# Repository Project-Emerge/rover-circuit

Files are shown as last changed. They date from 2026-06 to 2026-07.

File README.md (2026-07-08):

# Dropbot Circuit Board

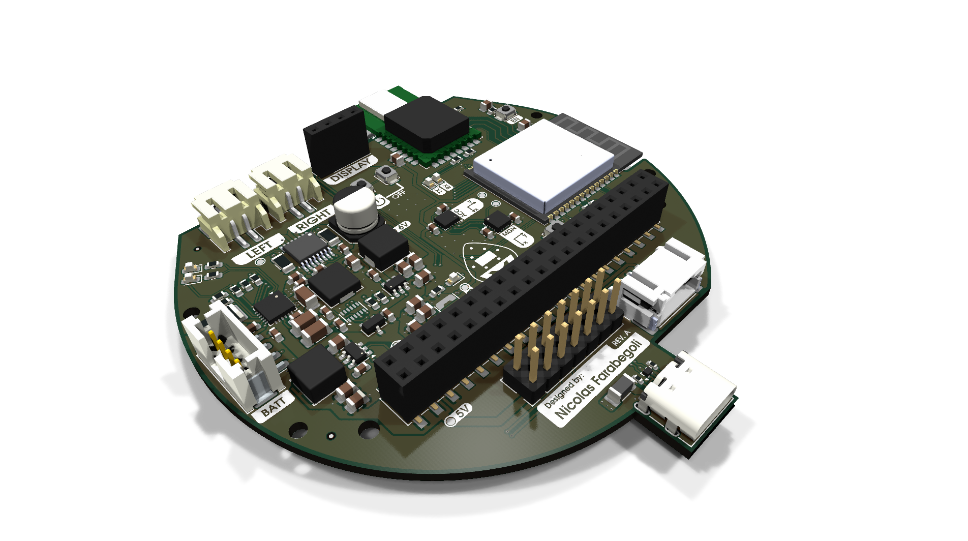
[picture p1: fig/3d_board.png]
3D View of the Board


## Scope of the Board

The Rover Circuit is a comprehensive controller board designed for robotics applications, specifically targeted at robot rovers. A key goal of this project is to make swarm robotics accessible to students, educators, and researchers, providing an affordable and easy-to-use platform for experimenting with multi-agent systems and decentralized control. 

It integrates dual-motor driving capabilities, 2-cell Li-ion battery management with USB-C charging, and provides multiple power domains (3.3V, 5V, 6V) for logic, sensors, and external compute modules like a Raspberry Pi. The board includes I2C and GPIO interfaces to facilitate communication with various sensors and control systems, making it a compact, all-in-one hardware platform for mobile robot development.

## Main Components & Features

* **Espressif ESP32-C6 (Microcontroller)**: The core processing unit of the board, offering Wi-Fi 6, Bluetooth LE, and IEEE 802.15.4 (Zigbee/Thread) connectivity. Its robust wireless capabilities are ideal for inter-robot communication in a swarm network.
* **Decawave DWM1000 (UWB Module)**: An Ultra-Wideband transceiver module designed for precise indoor localization, spatial awareness, and ranging between rovers. Crucial for coordinated swarm movements and mapping.
* **9-DOF Inertial Measurement Unit (IMU)**: 
  * *Bosch BMI270*: A 6-axis accelerometer and gyroscope for tracking movement and rotation.
  * *MEMSIC MMC5983MA*: A high-precision 3-axis magnetometer acting as a digital compass for absolute heading orientation.
* **TI BQ25887 (Battery Management)**: A 2-cell Li-ion boost-mode battery charger with integrated cell balancing and USB-C input support. It handles safe charging and power management for the entire rover.
* **TI DRV8833 (Motor Driver)**: A dual H-bridge motor driver capable of delivering 1.5A RMS per bridge. It is used to independently drive two DC motors (such as N20 motors) for locomotion.
* **STM6601 (Power Controller)**: A smart push-button on/off controller for robust hardware power management and user interaction.
* **Power Distribution System**: Dedicated voltage regulators generating 3.3V for internal logic and sensors, 6V for the motors, and a clean 5V output.
* **SBC Expansion & User Interface**: An expansion header capable of powering and interfacing with a Single Board Computer (e.g., Raspberry Pi) over 5V, along with a dedicated I2C connector for attaching an OLED display module.

These components work together to provide a complete, robust sensing, processing, and locomotion backend, allowing developers to focus on high-level swarm robotics software and decentralized algorithms without worrying about hardware integration.

## Sponsors

<a href="https://jlcpcb.com/">JLCPCB</a>
<a href="https://easyeda.com/">EasyEDA</a>

---

## License

MIT License - see LICENSE file for details.

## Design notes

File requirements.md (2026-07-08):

# Requirements

---

### General Requirements

### Mechanical Requirements

### Electrical Requirements

### Functional Requirements

### 2. General Board Overview

* **Application**: Robot rover controller with battery charging and motor driving capabilities.
* **Target Enclosure**: Custom 3D-printed case with mounting points for motors, battery, and sensors.
* **Operating Temperature Range**: -20 °C to +60 °C.

---

### 3. Mechanical Requirements

* **Board Dimensions**: ?? mm × ?? mm (to fit within the enclosure).
* **Mounting Holes**: 4 holes for M2 screws, located at the two sides of the board.
* **Thickness**: Standard 1.6 mm PCB thickness.
* **Keep-out Zones**: 5 mm from the edges for mounting clearance; No components in the center bottom side (battery slot). No components closer than 3 mm to the mounting holes.

---

### 4. Electrical Requirements

#### 4.1 Power Domains
* **Input Voltage**: Two-cell Li-ion battery (7.4 V nominal) with USB-C charging support.
* **Internal Voltage Rails**: 3.3 V for logic and sensors, 6 V for motors, and regulated 5 V for external Raspberry Pi connection.
* **Current Requirements**: Up to 2 A for motors, 1 A for sensors and logic.

#### 4.2 Interfaces
* **I2C**: For communication with sensors and battery management.
* **GPIO**: For motor control signals and status LEDs.
* **USB-C**: For charging and potential data communication with a host computer.
* **Motor Outputs**: Two H-bridge outputs for controlling two DC motors.

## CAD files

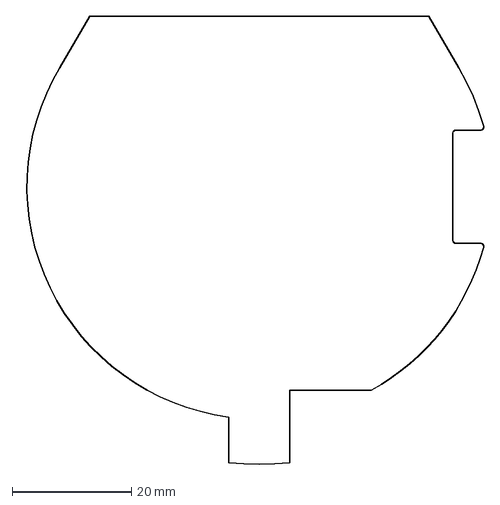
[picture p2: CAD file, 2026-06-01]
pcb_layout.dxf
78.5 x 75.4 mm

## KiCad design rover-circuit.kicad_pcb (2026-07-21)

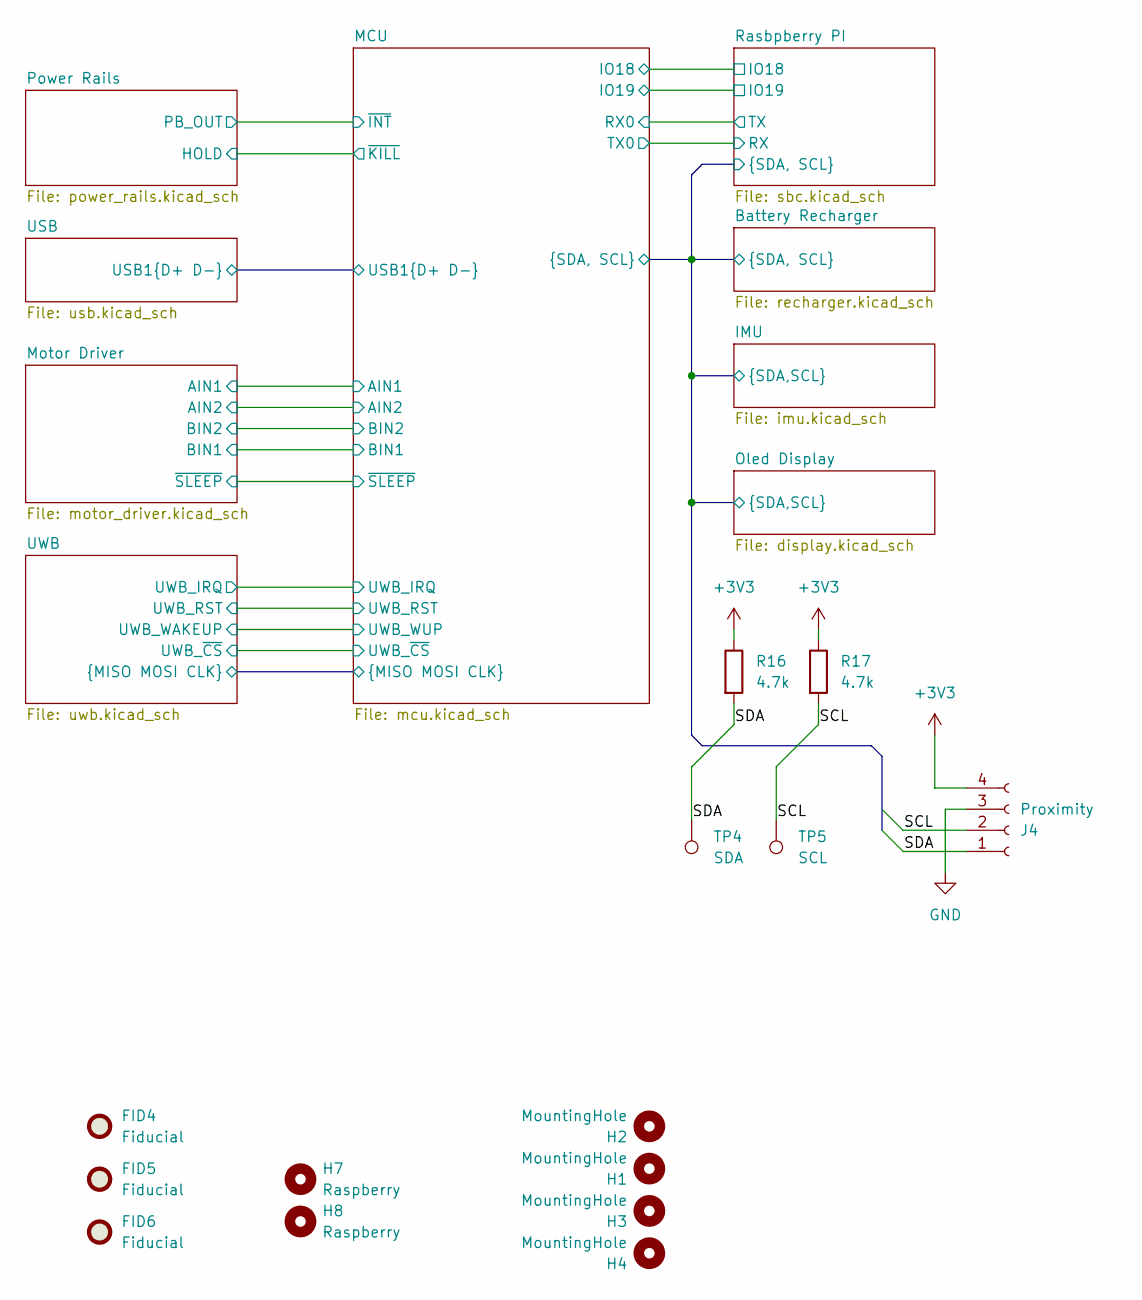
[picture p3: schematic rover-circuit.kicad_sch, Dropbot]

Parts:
FID4, FID5, FID6: Fiducial; Fiducial_0.5mm_Mask1mm
H1, H2, H3, H4: MountingHole; MountingHole_2.2mm_M2
H7, H8: Raspberry; MountingHole_2.5mm
J4: Proximity; JST_PH_S4B-PH-SM4-TB_1x04-1MP_P2.00mm_Horizontal; MPN S4B-PH-SM4-TB(LF)(SN); LCSC C265102
R16, R17: 4.7k; R_0603_1608Metric; MPN GPR060347; LCSC C25999
TP4: SDA; TestPoint_Pad_D1.0mm
TP5: SCL; TestPoint_Pad_D1.0mm

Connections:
+3V3: J4.4, R16.1, R17.1; also elsewhere on the board
/Battery Recharger/SCL: J4.2, R17.2, TP5.1 (1_1); also elsewhere on the board
/Battery Recharger/SDA: J4.1, R16.2, TP4.1 (1_1); also elsewhere on the board
GND: J4.3; also elsewhere on the board

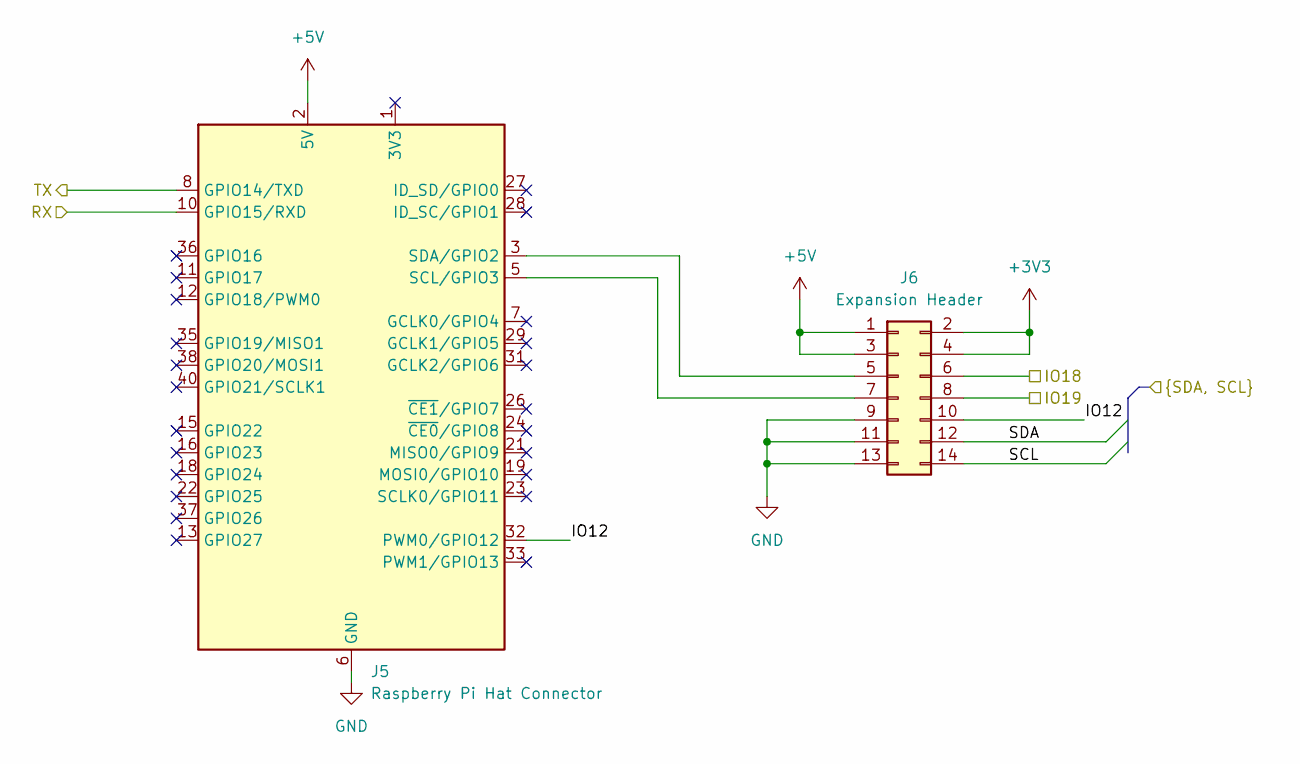
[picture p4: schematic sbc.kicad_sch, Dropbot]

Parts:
J5: Raspberry Pi Hat Connector; PinSocket_2x20_P2.54mm_Vertical_SMD; MPN 953240-2000-AR-PR; LCSC C22436166
J6: Expansion Header; PinHeader_2x07_P2.54mm_Vertical; MPN 61201421621; LCSC C492424

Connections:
+3V3: J6.2, J6.4; also elsewhere on the board
+5V: J5.2 (5V), J5.4 (5V), J6.1, J6.3; also elsewhere on the board
/Battery Recharger/SCL: J6.14; also elsewhere on the board
/Battery Recharger/SDA: J6.12; also elsewhere on the board
/MCU/IO18: J6.6; also elsewhere on the board
/MCU/IO19: J6.8; also elsewhere on the board
/MCU/RX0: J5.8 (GPIO14/TXD); also elsewhere on the board
/MCU/TX0: J5.10 (GPIO15/RXD); also elsewhere on the board
/Rasbpberry PI/IO12: J5.32 (PWM0/GPIO12), J6.10
GND: J5.6 (GND), J5.9 (GND), J5.14 (GND), J5.20 (GND), J5.25 (GND), J5.30 (GND), J5.34 (GND), J5.39 (GND), J6.9, J6.11, J6.13; also elsewhere on the board
unnamed: J5.5 (SCL/GPIO3), J6.7
unnamed: J5.3 (SDA/GPIO2), J6.5

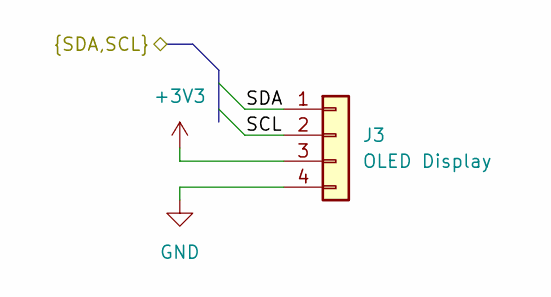
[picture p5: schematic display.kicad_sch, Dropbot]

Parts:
J3: OLED Display; PinSocket_1x04_P2.54mm_Vertical; MPN PPTC041LFBN-RC; LCSC C2718488

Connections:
+3V3: J3.3; also elsewhere on the board
/Battery Recharger/SCL: J3.2; also elsewhere on the board
/Battery Recharger/SDA: J3.1; also elsewhere on the board
GND: J3.4; also elsewhere on the board

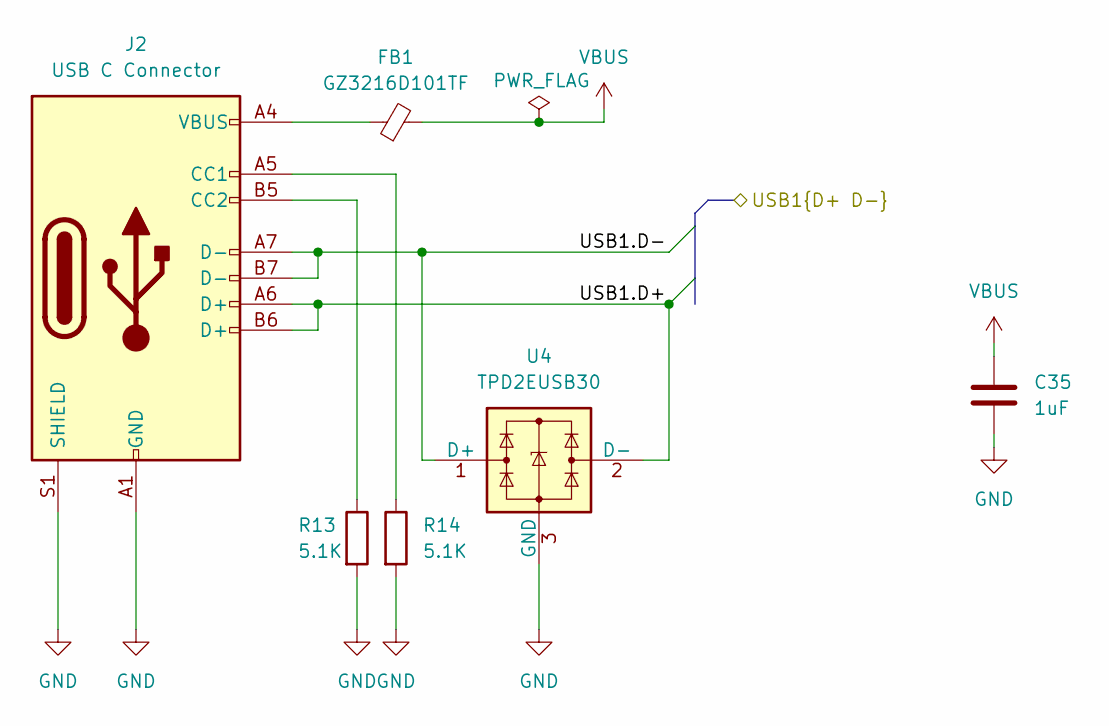
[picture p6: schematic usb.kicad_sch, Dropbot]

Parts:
C35: 1uF; C_0603_1608Metric; MPN GPC0603105; LCSC C5673
FB1: GZ3216D101TF; L_1206_3216Metric; MPN BLM31PG500SN1L; LCSC C369799
J2: USB C Connector; USB_C_Receptacle_G-Switch_GT-USB-7010ASV; MPN GT-USB-7010ASV; LCSC C2988369
R13, R14: 5.1K; R_0402_1005Metric; MPN GPR040251; LCSC C25905
U4: TPD2EUSB30; Texas_DRT-3; MPN TPD2EUSB30ADRTR; LCSC C94934

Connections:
/MCU/USB1.D+: J2.A6 (D+), J2.B6 (D+), U4.2 (D-); also elsewhere on the board
/MCU/USB1.D-: J2.A7 (D-), J2.B7 (D-), U4.1 (D+); also elsewhere on the board
GND: C35.2, J2.A1 (GND), J2.A12 (GND), J2.B1 (GND), J2.B12 (GND), J2.S1 (SHIELD), R13.2, R14.2, U4.3 (GND); also elsewhere on the board
unnamed: FB1.1, J2.A4 (VBUS), J2.A9 (VBUS), J2.B4 (VBUS), J2.B9 (VBUS)
unnamed: J2.A5 (CC1), R14.1
unnamed: J2.B5 (CC2), R13.1
VBUS: C35.1, FB1.2; also elsewhere on the board

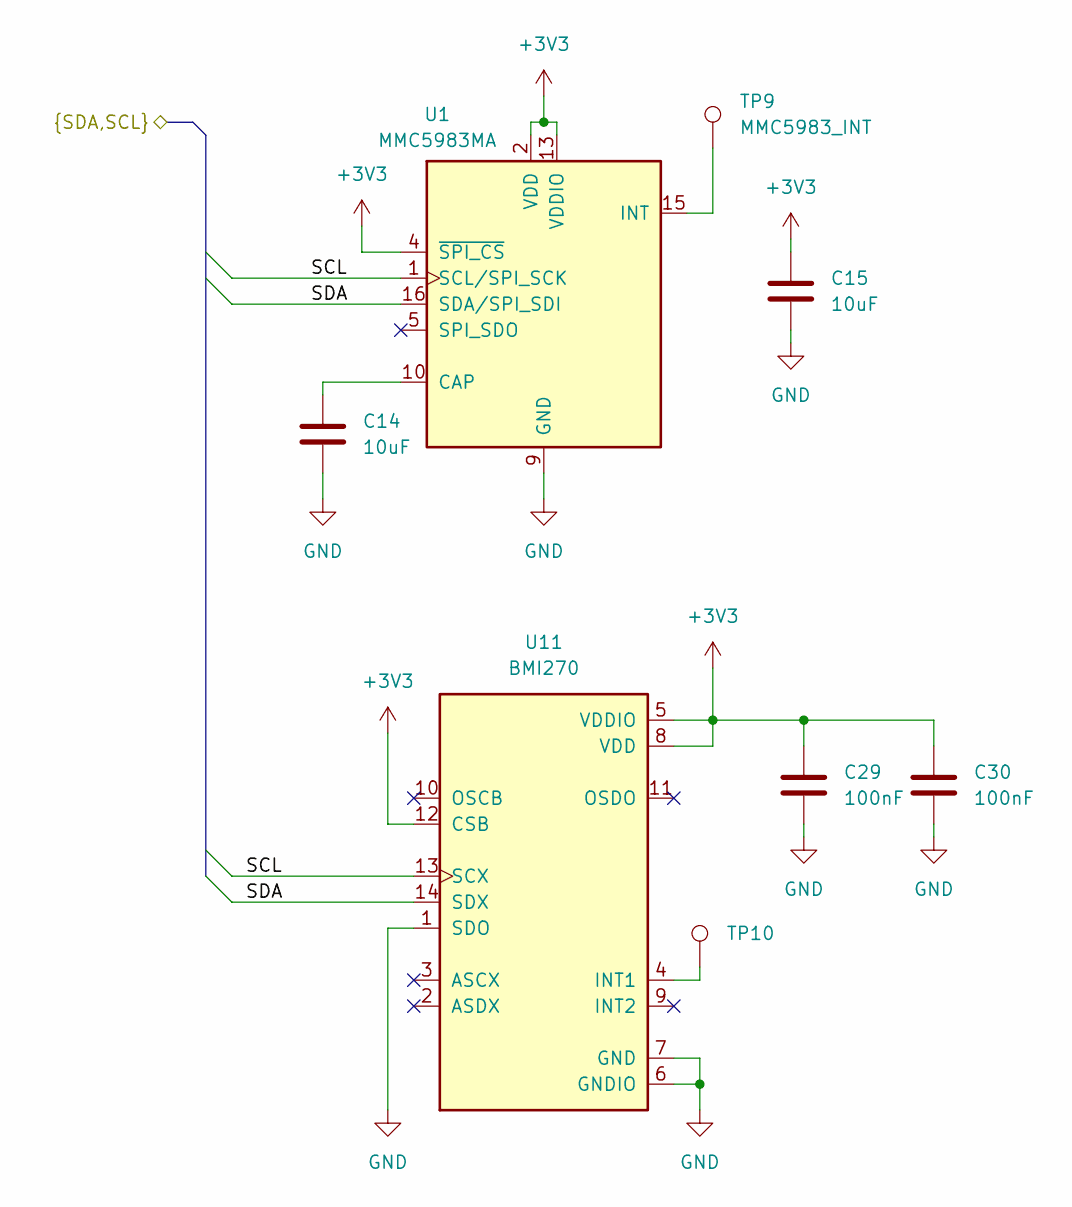
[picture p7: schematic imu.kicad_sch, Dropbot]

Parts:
C14, C15: 10uF; C_0603_1608Metric; MPN GPC0603106; LCSC C962136
C29, C30: 100nF; C_0603_1608Metric; MPN GPC0603104; LCSC C14663
TP9: MMC5983_INT; TestPoint_Pad_D1.0mm
TP10: INT1; TestPoint_Pad_D1.0mm
U1: MMC5983MA; LGA-16_3x3mm_P0.5mm; PARTREV A; LCSC C404329
U11: BMI270; Bosch_LGA-14_3x2.5mm_P0.5mm; MPN BMI270; LCSC C2836813

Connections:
+3V3: C15.1, C29.1, C30.1, U1.2 (VDD), U1.4 (~SPI_CS), U1.13 (VDDIO), U11.5 (VDDIO), U11.8 (VDD), U11.12 (CSB); also elsewhere on the board
/Battery Recharger/SCL: U1.1 (SCL/SPI_SCK), U11.13 (SCX); also elsewhere on the board
/Battery Recharger/SDA: U1.16 (SDA/SPI_SDI), U11.14 (SDX); also elsewhere on the board
GND: C14.2, C15.2, C29.2, C30.2, U1.9 (GND), U1.11 (GND), U11.1 (SDO), U11.6 (GNDIO), U11.7 (GND); also elsewhere on the board
unnamed: C14.1, U1.10 (CAP)
unnamed: TP9.1 (1_1), U1.15 (INT)
unnamed: TP10.1 (1_1), U11.4 (INT1)

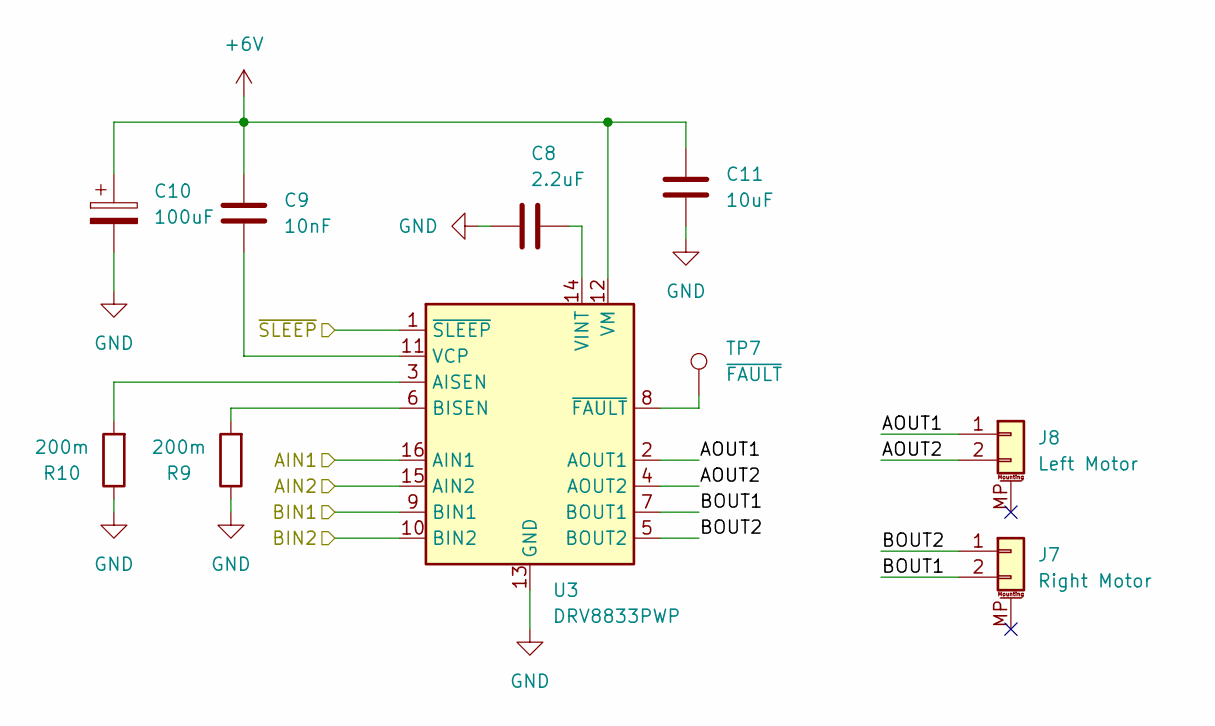
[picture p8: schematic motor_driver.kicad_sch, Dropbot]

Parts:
C8: 2.2uF; C_0603_1608Metric; MPN GPC0603225; LCSC C23630
C9: 10nF; C_0603_1608Metric; MPN GPC0603103; LCSC C1589
C10: 100uF; CP_Elec_6.3x5.4; MPN EEE-1CA101SP; LCSC C2887276
C11: 10uF; C_0805_2012Metric; MPN GPC0805106; LCSC C326595
J7: Right Motor; JST_PH_S2B-PH-SM4-TB_1x02-1MP_P2.00mm_Horizontal; MPN S2B-PH-SM4-TB(LF)(SN); LCSC C295747
J8: Left Motor; JST_PH_S2B-PH-SM4-TB_1x02-1MP_P2.00mm_Horizontal; MPN S2B-PH-SM4-TB(LF)(SN); LCSC C295747
R9, R10: 200m; R_1206_3216Metric; MPN ERJ-8BWFR200V; LCSC C5127778
TP7: ~{FAULT}; TestPoint_Pad_D1.0mm
U3: DRV8833PWP; HTSSOP-16-1EP_4.4x5mm_P0.65mm_EP3.4x5mm_Mask2.46x2.31mm_The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; MPN DRV8833PWPR; LCSC C50506

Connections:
+6V: C9.1, C10.1, C11.1, U3.12 (VM); also elsewhere on the board
/MCU/AIN1: U3.16 (AIN1); also elsewhere on the board
/MCU/AIN2: U3.15 (AIN2); also elsewhere on the board
/MCU/BIN1: U3.9 (BIN1); also elsewhere on the board
/MCU/BIN2: U3.10 (BIN2); also elsewhere on the board
/MCU/~SLEEP: U3.1 (~SLEEP); also elsewhere on the board
/Motor Driver/AOUT1: J8.1, U3.2 (AOUT1)
/Motor Driver/AOUT2: J8.2, U3.4 (AOUT2)
/Motor Driver/BOUT1: J7.2, U3.7 (BOUT1)
/Motor Driver/BOUT2: J7.1, U3.5 (BOUT2)
GND: C8.2, C10.2, C11.2, R9.1, R10.1, U3.13 (GND), U3.17 (GND); also elsewhere on the board
unnamed: R10.2, U3.3 (AISEN)
unnamed: R9.2, U3.6 (BISEN)
unnamed: C9.2, U3.11 (VCP)
unnamed: C8.1, U3.14 (VINT)
unnamed: TP7.1 (1_1), U3.8 (~FAULT)

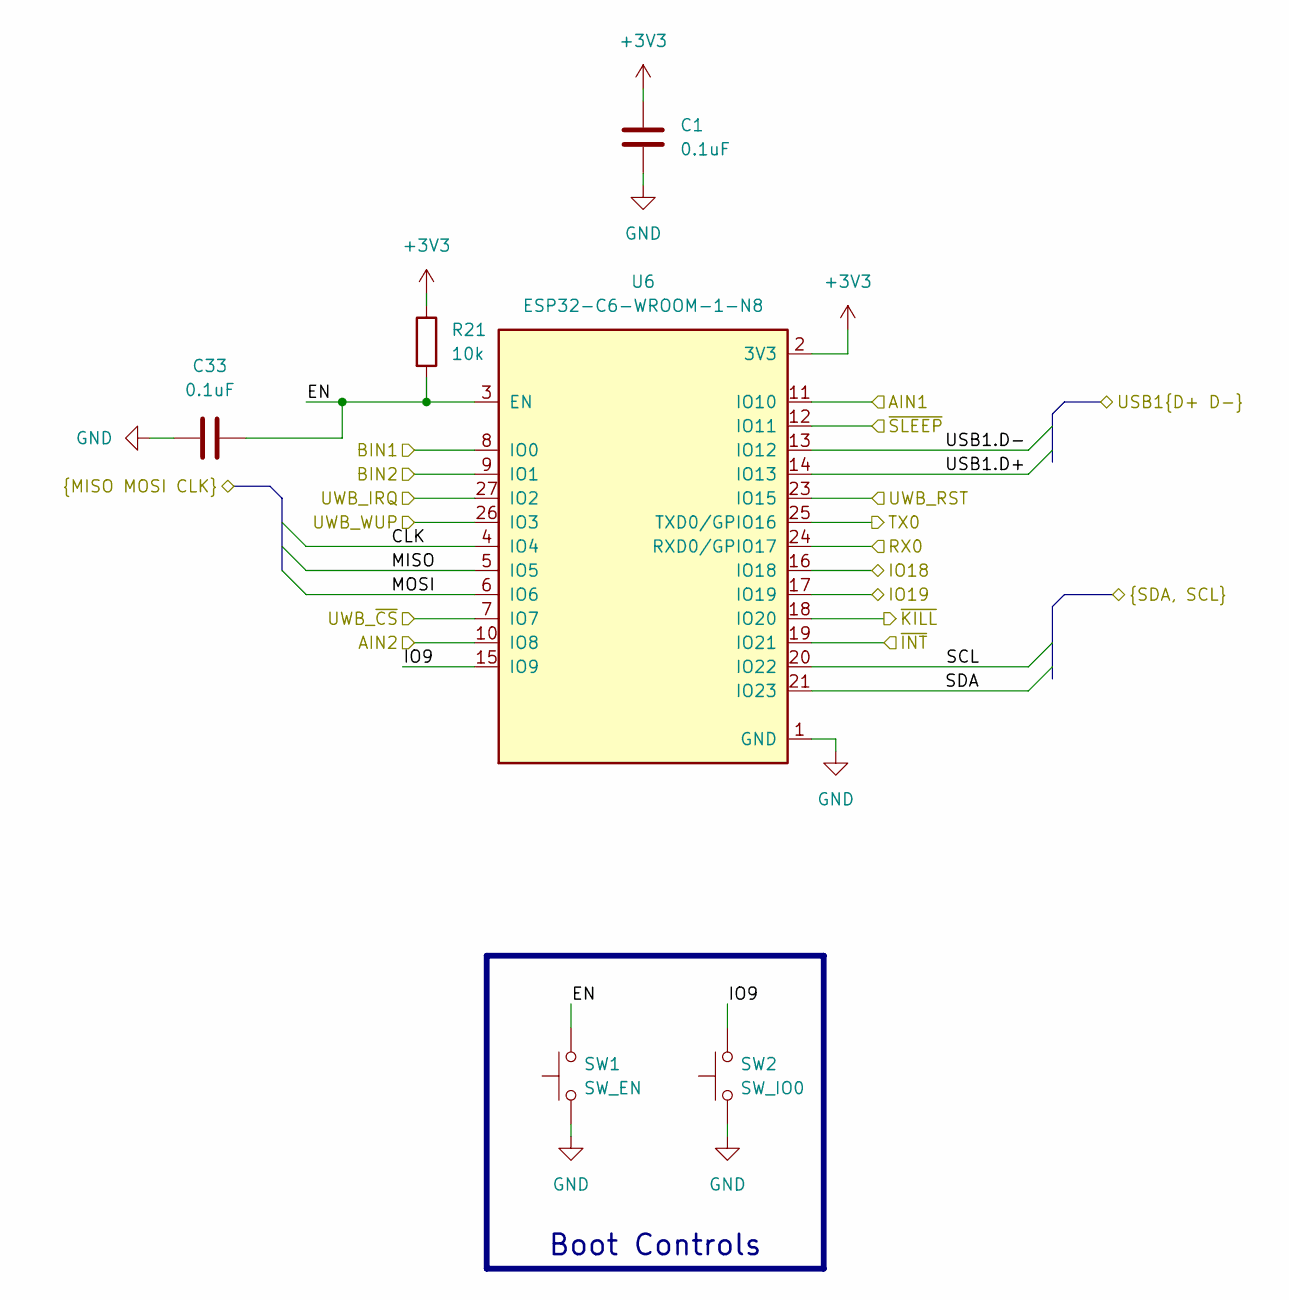
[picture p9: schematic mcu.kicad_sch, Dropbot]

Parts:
C1: 0.1uF; C_0805_2012Metric; LCSC C49678
C33: 0.1uF; C_0805_2012Metric; MPN GPC0805104; LCSC C49678
R21: 10k; R_0603_1608Metric; MPN GPR060310K; LCSC C15401
SW1: SW_EN; SW_SPST_B3U-1000P; MPN B3U-1000P; LCSC C231329
SW2: SW_IO0; SW_SPST_B3U-1000P; MPN B3U-1000P; LCSC C231329
U6: ESP32-C6-WROOM-1-N8; XCVR_ESP32-C6-WROOM-1-N8; PARTREV 1.0; LCSC C5366877

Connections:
+3V3: C1.1, R21.1, U6.2 (3V3); also elsewhere on the board
/Battery Recharger/SCL: U6.20 (IO22); also elsewhere on the board
/Battery Recharger/SDA: U6.21 (IO23); also elsewhere on the board
/MCU/AIN1: U6.11 (IO10); also elsewhere on the board
/MCU/AIN2: U6.10 (IO8); also elsewhere on the board
/MCU/BIN1: U6.8 (IO0); also elsewhere on the board
/MCU/BIN2: U6.9 (IO1); also elsewhere on the board
/MCU/CLK: U6.4 (IO4); also elsewhere on the board
/MCU/EN: C33.2, R21.2, SW1.2, U6.3 (EN)
/MCU/IO9: SW2.2, U6.15 (IO9)
/MCU/IO18: U6.16 (IO18); also elsewhere on the board
/MCU/IO19: U6.17 (IO19); also elsewhere on the board
/MCU/MISO: U6.5 (IO5); also elsewhere on the board
/MCU/MOSI: U6.6 (IO6); also elsewhere on the board
/MCU/RX0: U6.24 (RXD0/GPIO17); also elsewhere on the board
/MCU/TX0: U6.25 (TXD0/GPIO16); also elsewhere on the board
/MCU/USB1.D+: U6.14 (IO13); also elsewhere on the board
/MCU/USB1.D-: U6.13 (IO12); also elsewhere on the board
/MCU/UWB_IRQ: U6.27 (IO2); also elsewhere on the board
/MCU/UWB_RST: U6.23 (IO15); also elsewhere on the board
/MCU/UWB_WUP: U6.26 (IO3); also elsewhere on the board
/MCU/UWB_~CS: U6.7 (IO7); also elsewhere on the board
/MCU/~INT: U6.19 (IO21); also elsewhere on the board
/MCU/~KILL: U6.18 (IO20); also elsewhere on the board
/MCU/~SLEEP: U6.12 (IO11); also elsewhere on the board
GND: C1.2, C33.1, SW1.1, SW2.1, U6.1 (GND), U6.28 (GND), U6.29_1 (GND), U6.29_2 (GND), U6.29_3 (GND), U6.29_4 (GND), U6.29_5 (GND), U6.29_6 (GND), U6.29_7 (GND), U6.29_8 (GND), U6.29_9 (GND); also elsewhere on the board

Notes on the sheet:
Boot Controls

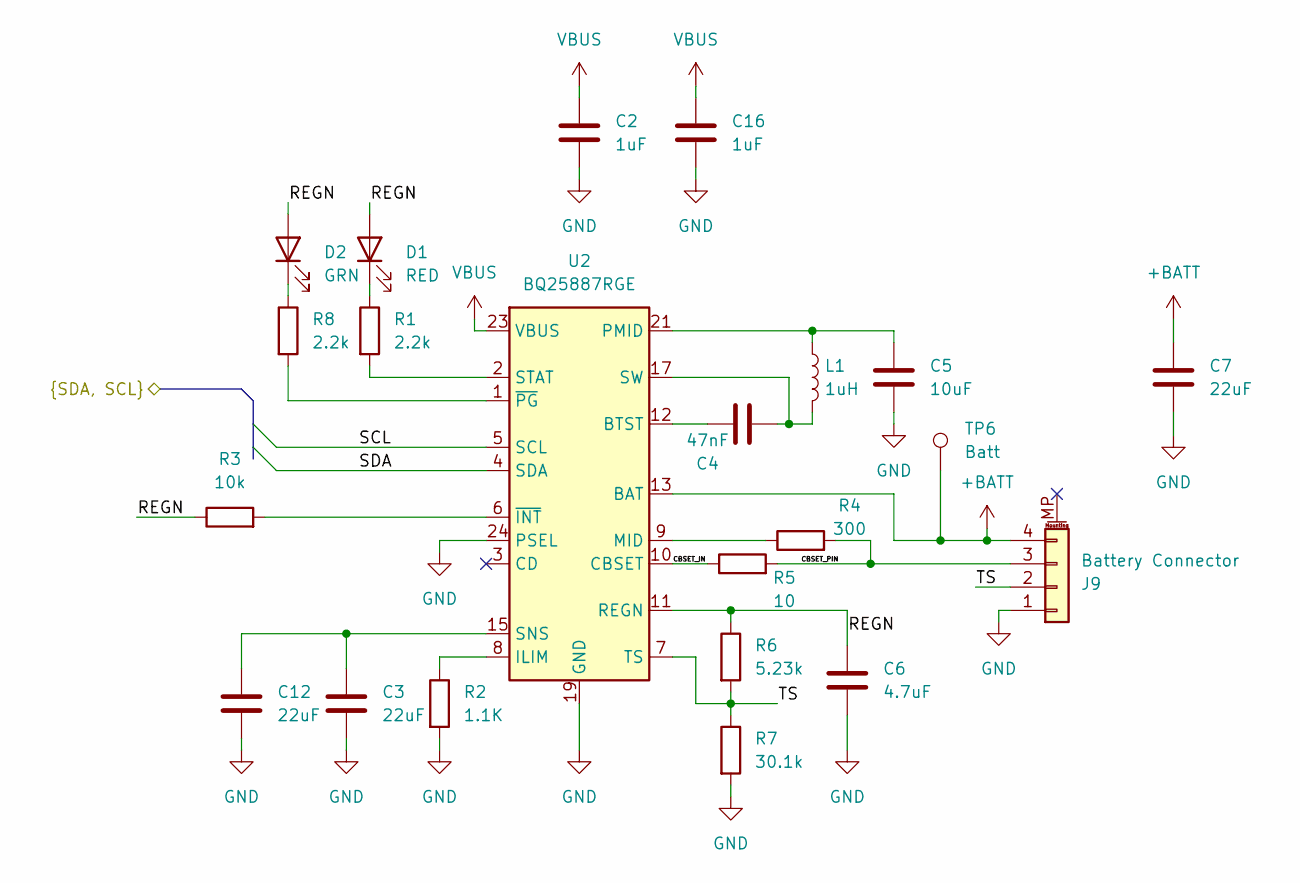
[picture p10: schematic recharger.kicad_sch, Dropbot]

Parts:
C2, C16: 1uF; C_0603_1608Metric; MPN GPC0603105; LCSC C5673
C3, C12: 22uF; C_1206_3216Metric; MPN GPC1206226; LCSC C53084537
C4: 47nF; C_0603_1608Metric; MPN GPC0603473; LCSC C1622
C5: 10uF; C_1206_3216Metric; MPN GPC1206106; LCSC C13585
C6: 4.7uF; C_0603_1608Metric; MPN GPC0603475; LCSC C69335
C7: 22uF; C_0603_1608Metric; MPN GRM188C61E226ME01D; LCSC C86295
D1: RED; LED_0603_1608Metric; MPN 150060RS75000; LCSC C2286
D2: GRN; LED_0603_1608Metric; MPN 150060VS75000; LCSC C965805
J9: Battery Connector; JST_PH_B4B-PH-SM4-TB_1x04-1MP_P2.00mm_Vertical; MPN B4B-PH-SM4-TB(LF)(SN); LCSC C160354
L1: 1uH; L_Sunlord_MWSA0518S; LCSC C475532
R1, R8: 2.2k; R_0603_1608Metric; MPN GPR060322; LCSC C4190
R2: 1.1K; R_0603_1608Metric; MPN GPR060311; LCSC C22764
R3: 10k; R_0603_1608Metric; MPN GPR060310K; LCSC C15401
R4: 300; R_0603_1608Metric; MPN GPR0603300R; LCSC C2930092
R5: 10; R_2512_6332Metric; MPN CRM2512-FX-10R0ELF; LCSC C840605
R6: 5.23k; R_0603_1608Metric; MPN GPR0603523; LCSC C23068
R7: 30.1k; R_0603_1608Metric; MPN GPR0603301; LCSC C23000
TP6: Batt; TestPoint_Pad_D1.0mm
U2: BQ25887RGE; Texas_RGE0024H_VQFN-24-1EP_4x4mm_P0.5mm_EP2.7x2.7mm; MPN BQ25887RGER; LCSC C2761614

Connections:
+BATT: C7.1, J9.4, TP6.1 (1_1), U2.13 (BAT), U2.14 (BAT); also elsewhere on the board
/Battery Recharger/CBSET_IN: R5.1, U2.10 (CBSET)
/Battery Recharger/CBSET_PIN: J9.3, R4.2, R5.2
/Battery Recharger/REGN: C6.1, D1.2 (A), D2.2 (A), R3.1, R6.1, U2.11 (REGN)
/Battery Recharger/SCL: U2.5 (SCL); also elsewhere on the board
/Battery Recharger/SDA: U2.4 (SDA); also elsewhere on the board
/Battery Recharger/TS: J9.2, R6.2, R7.1, U2.7 (TS)
GND: C2.2, C3.2, C5.2, C6.2, C7.2, C12.2, C16.2, J9.1, R2.2, R7.2, U2.19 (GND), U2.20 (GND), U2.24 (PSEL), U2.25 (GND); also elsewhere on the board
unnamed: C4.1, L1.2, U2.17 (SW), U2.18 (SW)
unnamed: C5.1, L1.1, U2.21 (PMID), U2.22 (PMID)
unnamed: C3.1, C12.1, U2.15 (SNS), U2.16 (SNS)
unnamed: D1.1 (K), R1.1
unnamed: D2.1 (K), R8.1
unnamed: C4.2, U2.12 (BTST)
unnamed: R2.1, U2.8 (ILIM)
unnamed: R4.1, U2.9 (MID)
unnamed: R1.2, U2.2 (STAT)
unnamed: R3.2, U2.6 (~INT)
unnamed: R8.2, U2.1 (~PG)
VBUS: C2.1, C16.1, U2.23 (VBUS); also elsewhere on the board

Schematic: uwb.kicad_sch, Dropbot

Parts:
C27: 0.1uF; C_0805_2012Metric; MPN GPC0805104; LCSC C49678
D5, D6: BLUE; LED_0603_1608Metric; MPN 150060BS75000; LCSC C965807
DWM1: DWM1000; MPN DWM1000
R18: 10k; R_0603_1608Metric; MPN GPR060310K; LCSC C15401
R19, R20: 470; R_0603_1608Metric; MPN GPR0603470R; LCSC C23179

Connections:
+3V3: C27.1, DWM1.5 (VDDAON), DWM1.6 (VDD3V3), DWM1.7 (VDD3V3); also elsewhere on the board
/MCU/CLK: DWM1.20 (SPICLK); also elsewhere on the board
/MCU/MISO: DWM1.19 (SPIMISO); also elsewhere on the board
/MCU/MOSI: DWM1.18 (SPIMOSI); also elsewhere on the board
/MCU/UWB_IRQ: DWM1.22 (IRQ/GPIO8), R18.1; also elsewhere on the board
/MCU/UWB_RST: DWM1.3 (~RST); also elsewhere on the board
/MCU/UWB_WUP: DWM1.2 (WAKEUP); also elsewhere on the board
/MCU/UWB_~CS: DWM1.17 (~SPICS); also elsewhere on the board
GND: C27.2, D5.1 (K), D6.1 (K), DWM1.8 (VSS), DWM1.16 (VSS), DWM1.21 (VSS), DWM1.23 (VSS), DWM1.24 (VSS), R18.2; also elsewhere on the board
unnamed: D5.2 (A), R19.2
unnamed: D6.2 (A), R20.2
unnamed: DWM1.13 (GPIO2/RXLED), R19.1
unnamed: DWM1.12 (GPIO3/TXLED), R20.1

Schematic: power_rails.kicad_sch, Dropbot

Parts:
C13, C19: 100nF; C_0603_1608Metric; MPN GPC0603104; LCSC C14663
C17, C20, C21, C23, C24, C28: 22uF; C_0805_2012Metric; MPN GPC0805226; LCSC C296720
C18, C22, C25: 10uF; C_0805_2012Metric; MPN GPC0805106; LCSC C326595
C26: 2.2uF; C_0603_1608Metric; MPN GPC0603225; LCSC C415535
C31: 1uF; C_0603_1608Metric; MPN GPC0603105; LCSC C5360793
C32: 1uF; C_0603_1608Metric; MPN GPC0603105; LCSC C5673
C34: 470nF; C_0603_1608Metric; LCSC C1623
D3: LED; LED_0603_1608Metric; MPN 150060RS75000; LCSC C2286
L2: 2.2uH; L_Coilcraft_LPS3010; MPN LPS3015-222MRC; LCSC C2844756
L3: 4.7uH; L_Chilisin_BWVS00505030; MPN LVS505040-4R7M-N; LCSC C108284
L4: 10uH; L_Sunlord_MWSA0503S; LCSC C408412
R11: 64.9k; R_0603_1608Metric; MPN GPR0603649; LCSC C14891
R12: 10k; R_0603_1608Metric; MPN GPR060310K; LCSC C15401
R15: 100K; R_0603_1608Metric; MPN GPR0603100K; LCSC C25803
SW3: ~{SR}; SW_SPST_B3U-1000P; MPN B3U-1000P; LCSC C231329
SW4: ~{PB}; SW_SPST_B3U-1000P; MPN B3U-1000P; LCSC C231329
TP1: 3V3 TP; TestPoint_Pad_D1.0mm
TP2: 5V TP; TestPoint_Pad_D1.0mm
TP3: 6V TP; TestPoint_Pad_D1.0mm
U5: AP63200WU; TSOT-23-6; MPN AP63200WU-7; LCSC C2071868
U7: AP63205WU; TSOT-23-6; MPN AP63205WU-7; LCSC C2071056
U8: STM6601CM2DDM6F; TDFN-12_2x3mm_P0.5mm; MPN STM6601CM2DDM6F; LCSC C155599
U9: TPS62162DSG; WSON-8-1EP_2x2mm_P0.5mm_EP0.9x1.6mm_ThermalVias; MPN TPS62162DSGR; LCSC C40256
U12: MCP1799T-5002H/TT; SOT-23; MPN MCP1799T-5002H/TT; LCSC C2890492

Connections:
+3V3: C17.1, C28.1, L2.2, R15.1, TP1.1 (1_1), U9.5 (FB), U9.6 (VOS); also elsewhere on the board
+5V: C20.1, C21.1, L3.2, TP2.1 (1_1), U7.1 (FB); also elsewhere on the board
+6V: C23.1, C24.1, L4.2, R11.1, TP3.1 (1_1); also elsewhere on the board
+BATT: C18.1, C22.1, C25.1, C31.1, U5.3 (IN), U7.3 (IN), U9.2 (VIN), U12.3 (VI); also elsewhere on the board
/MCU/~INT: U8.8 (~PB_OUT); also elsewhere on the board
/MCU/~KILL: U8.4 (PS_HOLD); also elsewhere on the board
/Power Rails/STM6601_EN: U5.2 (EN), U7.2 (EN), U8.9 (~EN/EN), U9.3 (EN)
GND: C17.2, C18.2, C20.2, C21.2, C22.2, C23.2, C24.2, C25.2, C26.2, C28.2, C31.2, C32.2, C34.2, R12.2, SW3.1, SW4.1, U5.4 (GND), U7.4 (GND), U8.12 (GND), U9.1 (PGND), U9.4 (AGND), U9.9 (PAD), U12.1 (GND); also elsewhere on the board
unnamed: D3.2 (A), R15.2
unnamed: D3.1 (K), U9.8 (PG)
unnamed: C13.1, U5.6 (BST)
unnamed: R11.2, R12.1, U5.1 (FB)
unnamed: C13.2, L4.1, U5.5 (SW)
unnamed: C19.1, U7.6 (BST)
unnamed: C19.2, L3.1, U7.5 (SW)
unnamed: C34.1, U8.5 (C_SRD)
unnamed: C32.1, U8.3 (Vref)
unnamed: SW4.2, U8.6 (~PB)
unnamed: SW3.2, U8.2 (~SR)
unnamed: L2.1, U9.7 (SW)
unnamed: C26.1, U8.1 (Vcc), U12.2 (VO)

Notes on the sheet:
6V Motor Rail
3V3 Rail
5V Rail

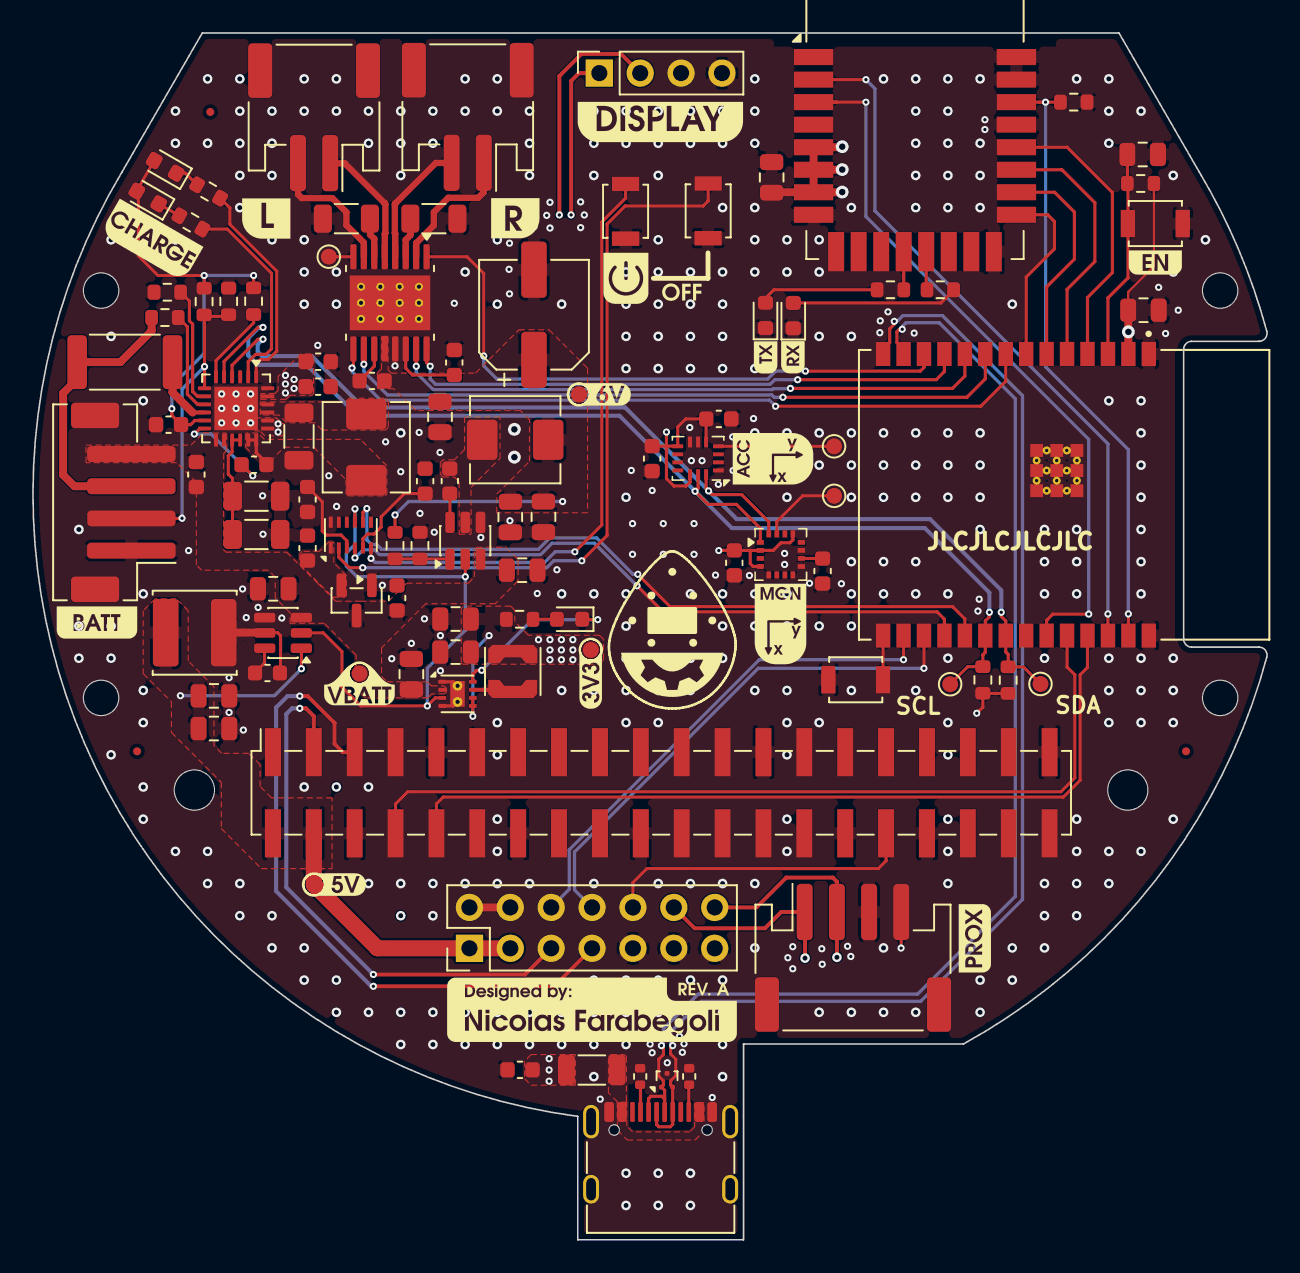
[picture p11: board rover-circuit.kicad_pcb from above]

Board: 4 copper layers, 76.7 x 75.0 mm, 108 parts (0 on the bottom side), 81 nets.

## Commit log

2025-07-11 feat: add schematic and board layout
    [HRO_TYPE-C-31-M-12.step, front_wheels.kicad_sch, rear_wheels.kicad_sch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]
2025-07-12 fix: separate standby pins for motor drivers
    [rover-circuit.kicad_pcb]
2025-07-13 feat: use different 3v3 regulator
    [rear_wheels.kicad_sch, rover-circuit.kicad_pcb, rover-circuit.kicad_sch]
2025-07-15 feat: change USB symbol and minor re-routing
    [rover-circuit.kicad_pcb, rover-circuit.kicad_sch]
2025-07-15 feat: suppress ERC warnings
    [rover-circuit.kicad_sch]
2025-07-15 feat: re-route a trace
    [rover-circuit.kicad_pcb]
2025-09-23 finalize components placement
    [battery_circuit.kicad_sch, pcb-outline.dxf, power_stage.kicad_sch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]
2025-09-28 some updates
    [ICM-42670-P.step, battery_circuit.kicad_sch, front_wheels.kicad_sch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]
2025-09-29 add uwb module
    [rover-circuit.kicad_pcb, rover-circuit.kicad_sch, uwb_module.kicad_sch]
2025-09-30 more on routing
    [battery_circuit.kicad_sch, rover-circuit.kicad_pcb]
2025-10-02 more routing
    [rover-circuit.kicad_pcb, rover-circuit.kicad_sch]
2025-10-03 some routing
    [rover-circuit.kicad_pcb]
2025-10-05 finalize routing
    [rover-circuit.kicad_pcb, rover-circuit.kicad_sch]
2025-10-06 complete routing
    [rover-circuit.kicad_pcb]
2026-03-16 start new design
    [mcu.kicad_sch, rover-circuit.kicad_sch, sbc.kicad_sch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]
2026-03-17 add recharger module
    [recharger.kicad_sch, rover-circuit.kicad_sch]
2026-04-02 update schematic
    [imu.kicad_sch, mcu.kicad_sch, motor_driver.kicad_sch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]
2026-04-05 add uwm and refactoring
    [TPS63802DLAR--3DModel-STEP-269445.STEP, TPS63802DLAR.step, display.kicad_sch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]
2026-04-24 improve design
    [Dropbot-2-Dropbot Body.3mf, Dropbot-2.FCStd, Dropbot.FCStd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]
2026-04-24 change component code part
    [mcu.kicad_sch]
2026-04-24 Add LCSC part for esp32
    [mcu.kicad_sch]
2026-04-28 design pcb and place components
    [pcb_components.dxf, power_rails.kicad_sch, rover-circuit.kicad_pcb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]
2026-05-01 moving on routing
    [TPS63802DLAR--3DModel-STEP-269445.STEP, TPS63802DLAR.step, motor_driver.kicad_sch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]
2026-05-01 update PCB
    [motor_driver.kicad_sch, recharger.kicad_sch, rover-circuit.kicad_pcb]
2026-05-02 more on layout
    [front_wheels.kicad_sch, rear_wheels.kicad_sch, recharger.kicad_sch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]
2026-05-02 remove old files
    [front_wheels.kicad_sch, rear_wheels.kicad_sch]
2026-05-03 some progress
    [rover-circuit.kicad_pcb, rover-circuit.kicad_sch]
2026-05-04 more on routing and schematic
    [motor_driver.kicad_sch, power_rails.kicad_sch, rover-circuit.kicad_pcb]
2026-05-05 some improvements
    [rover-circuit.kicad_pcb]
2026-05-13 progress on routing
    [imu.kicad_sch, mcu.kicad_sch, recharger.kicad_sch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]
2026-05-17 consolidated routing
    [mcu.kicad_sch, rover-circuit.kicad_pcb, rover-circuit.kicad_sch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]
2026-05-17 complete routing and validated ERC/DRC
    [Dropbot-2-Dropbot Body.3mf, Dropbot-2.FCStd, Dropbot.FCStd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]
2026-05-18 improved routing
    [rover-circuit.kicad_pcb, rover-circuit.kicad_sch]
2026-05-18 populated some components
    [rover-circuit.kicad_pcb]
2026-05-18 tentative automatic population
    [imu.kicad_sch, mcu.kicad_sch, motor_driver.kicad_sch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]
2026-05-20 Consistent final layout
    [imu.kicad_sch, mcu.kicad_sch, motor_driver.kicad_sch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]
2026-05-27 annotate with LCSC components
    [display.kicad_sch, imu.kicad_sch, motor_driver.kicad_sch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]
2026-05-27 changed power layout
    [display.kicad_sch, imu.kicad_sch, motor_driver.kicad_sch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]
2026-05-27 some optimizations
    [rover-circuit.kicad_pcb]
2026-05-28 optimized space
    [recharger.kicad_sch, rover-circuit-Edge_Cuts.dxf, rover-circuit.kicad_pcb]
2026-05-28 finalized board
    [motor_driver.kicad_sch, pcb_layout.dxf, recharger.kicad_sch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]
2026-05-30 finalized component selection
    [display.kicad_sch, mcu.kicad_sch, power_rails.kicad_sch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]
2026-05-30 add jlcpcb components
    [rover-circuit-panelized-CuBottom.gbr, rover-circuit-panelized-EdgeCuts.gbr, rover-circuit-panelized-MaskBottom.gbr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]
2026-06-01 open hole in PCB under ESP32 for antenna
    [pcb_layout.dxf, rover-circuit.kicad_pcb]
2026-06-01 oriented components
    [rover-circuit-panelized-CuBottom.gbr, rover-circuit-panelized-EdgeCuts.gbr, rover-circuit-panelized-MaskBottom.gbr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]
2026-06-05 improved layout
    [rover-circuit.kicad_pcb]
2026-06-30 add MPS entries
    [display.kicad_sch, imu.kicad_sch, mcu.kicad_sch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]
2026-06-30 update MPN codes
    [imu.kicad_sch, mcu.kicad_sch, motor_driver.kicad_sch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]
2026-06-30 fix: update OAR from 0.075 to 0.125 and regenerate panel & gerbers
    [rover-circuit-panelized-CmtUser.gbr, rover-circuit-panelized-CuBottom.gbl, rover-circuit-panelized-CuBottom.gbr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]
2026-07-02 remove jlcpcb folder
    [rover-circuit-panelized-CmtUser.gbr, rover-circuit-panelized-CuBottom.gbl, rover-circuit-panelized-EdgeCuts.gm1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]
2026-07-03 finalizing pcb
    [imu.kicad_sch, mcu.kicad_sch, motor_driver.kicad_sch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]
2026-07-03 solve a problem with enable resistor and capacitor
    [mcu.kicad_sch, power_rails.kicad_sch, rover-circuit.kicad_pcb]
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2026-07-08 ci: change names to uploaded files in the release
    [HRO_TYPE-C-31-M-12.step, rover-circuit.step]
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2026-07-20 feat: switch to 4-layers and layout improvements
    [power_rails.kicad_sch, rover-circuit.kicad_pcb]
2026-07-20 feat: add motors label
    [rover-circuit.kicad_pcb]
2026-07-21 finalizing minor issues and improvements
    [mcu.kicad_sch, rover-circuit.kicad_pcb, usb.kicad_sch]
2026-07-21 add proper labels and minors improvements
    [rover-circuit.kicad_pcb, sbc.kicad_sch]
2026-07-21 fix: remove via on pad
    [rover-circuit.kicad_pcb]
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
